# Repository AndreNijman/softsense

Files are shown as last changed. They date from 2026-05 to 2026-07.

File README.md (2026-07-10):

# SoftSense — underwater self-sensing soft gripper

> 🏆 **Project complete (July 2026) — prize winner.** The full SoftSense project
> took home a prize at its competition. This repository is the finished,
> consolidated record: parametric CAD, FEA campaigns, the grip-texture and
> actuator studies, print profiles, ESP32 firmware and the Orange Pi
> controllers — everything in one place. (Formerly `gripper-cad`; the old
> GitHub URL redirects. The judge-facing engineering document is
> `SoftSense_Innovations_Documentation.docx`.)

<p align="center">
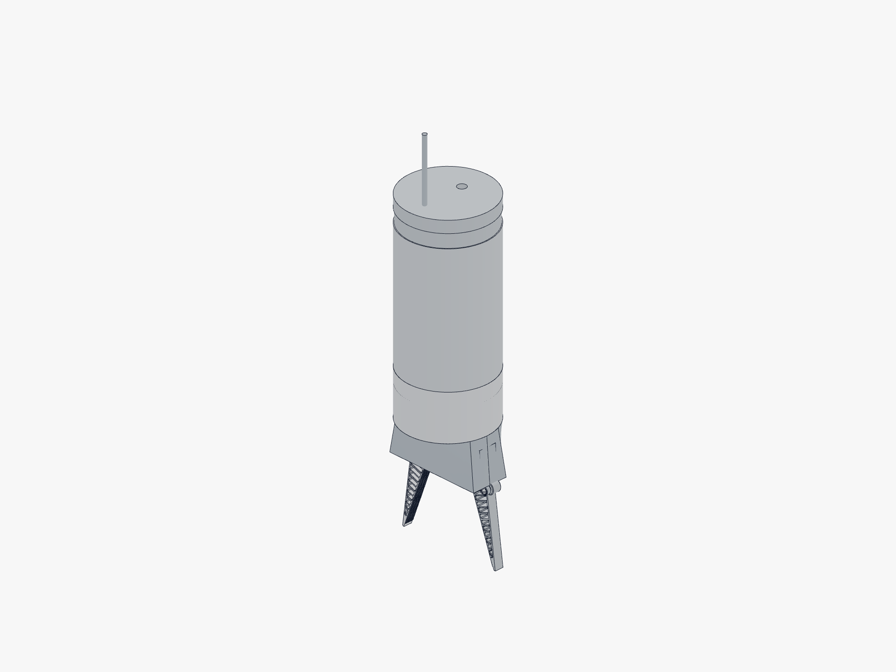
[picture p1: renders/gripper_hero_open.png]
SoftSense gripper, open
  
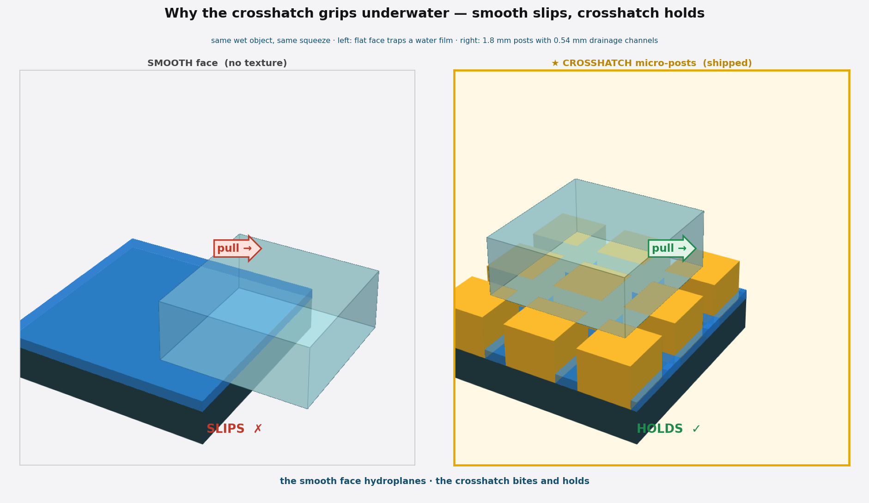
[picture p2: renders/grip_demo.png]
Grip demo — finger wrapping an object
  
  <br>
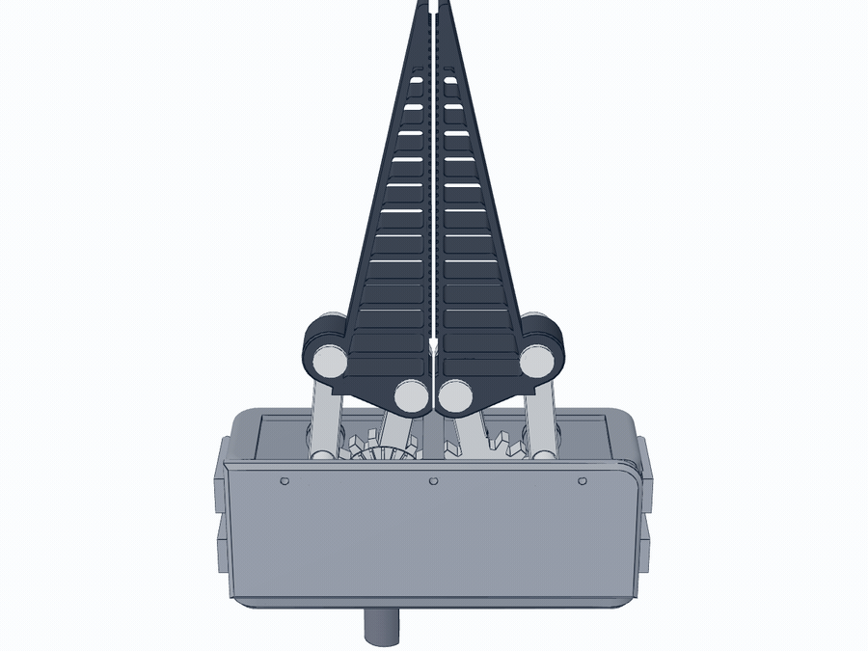
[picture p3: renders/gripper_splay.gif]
Open/close splay animation
  
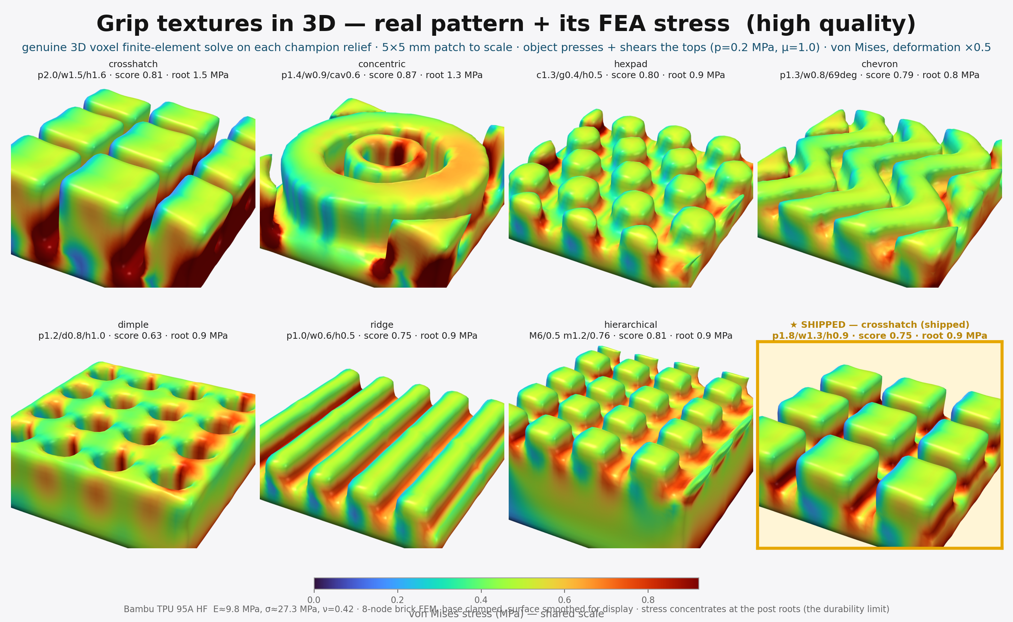
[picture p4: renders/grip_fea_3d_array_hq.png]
Voxel contact-FEA array
  
</p>

A robotic gripper with working single-DOF motion: **rotate one input shaft and
both fingers open/close symmetrically, splaying outward as they open.** The
jaws are **Fin Ray-style compliant fingers** (3D-printed in TPU with a
crosshatch micro-post grip texture) that bend and wrap *around* a grasped
object. The gear/linkage drive lives in a **flooded enclosure** designed for
**underwater** use (drain/flood holes, corrosion-resistant material choices —
`docs/UNDERWATER.md`).

**The SoftSense idea:** there is no dedicated force sensor. The **actuator is
the grip-force sensor** — motor current → torque → tip force through the
calibrated kinematic chain (`motor/SENSING.md`). The printed drivetrain is the
structural limit (`T_safe`), and the motor's current limit is its protection.

## Mechanism (one DOF)

- Two equal **spur gears** mesh on the centreline. The left gear (A_L) is
  driven through a **90° straight bevel pair**: a 12-tooth bevel gear fused on
  A_L's +Z face, driven by an integral 6-tooth bevel pinion (2.0 ratio,
  **module 1.8, 25° PA** — deliberately coarse, thick teeth from the gear-FEA
  strength pass) on a vertical **Ø15 input shaft**, so the drive **enters the
  housing from the bottom** while the fingers point up. The mesh
  counter-rotates the right gear: one shaft moves both fingers as a mirror pair.
- The input shaft's bottom end carries a **female Feetech 25T spline socket**
  (Ø5.9 serration, press-fit) — a **Feetech STS3250** bus servo presses
  straight in, no adapter horn. Caliper-verify the spline and print the fit
  coupon before committing (`gripper.py`, `SPLINE_*`).
- Each gear is the **crank of a non-parallelogram four-bar linkage**; the
  finger is rigid with the coupler. The link lengths give translate-apart
  **+ ~18° outward splay** over the travel, clear of any four-bar dead-point.
- Travel: closed (jaw faces ~1.6 mm apart) → open (~60 mm at the base,
  ~118 mm at the fingertips) at 1× scale.

## Fin Ray fingers (TPU)

Each finger is a compliant triangular truss — thin 1.2 mm contact beam, sharply
tapered 1.8 mm spine, 14 fine reversed-slant ribs — chosen by **multi-shape FEA**
to grasp **universally**: it distributes contact pressure along the whole finger
on flat/large objects and grips round objects evenly across a wide size range
(`fea/UNIVERSAL_FINGER.md`). The contact face carries a **crosshatch micro-post
grip texture** (1.8 mm posts + 0.54 mm drainage channels) — the empirical winner
among textures that actually tile the 10 mm blade, chosen by a wet-grip physics
model + sensitivity campaign with an honestly-documented override of the model's
raw winner (`grip/GRIP_TEXTURE.md §5`). Printed in **Bambu TPU 95A HF**
(measured ISO 527 data; ether-based TPU recommended for sustained immersion).

## Enclosure (flooded, underwater)

Rounded hollow housing; the vertical input shaft exits through two journal
bearings in the bottom wall, surrounded by a mounting flange with **4 × M4
bolt holes**. **Drain/flood holes** let it flood and drain — no trapped air,
pressure equalizes with depth. Top slots are sized to the measured arm sweep.

## Electronics & control

| Where | What |
|---|---|
| `firmware/` | **ESP32 controller (the shipped one)** — Waveshare General Driver for Robots. Boots its own Wi-Fi AP + captive web UI (OPEN/CLOSE, slider, live position/load/voltage/temp, on-flash calibration), drives the STS3250 on the built-in bus-servo port. **Stop-on-load** (gentle stop-on-contact) ported from the Pi controller. |
| `firmware/gamepad/` | **DualSense bridge** — a laptop-side script + page that turns a PS5 pad into a jog controller via the firmware's `/api/jog`. |
| `opi/` | **Orange Pi controllers** (3 LTS Wi-Fi-AP appliance + Ethernet-only Orange Pi PC/H3 variant) — the original offline web controller with stop-on-load, vendored pyserial, provisioning + deploy scripts. Superseded by the ESP32 after the Pi died, kept as a complete working alternative. |
| `motor/` | The **actuator & sensing study**: requirements → 12-agent survey → weighted selection (±50% sensitivity). Depth-rated pick: DYNAMIXEL XW540-T260; the built demonstrator runs the Feetech STS3250 direct-spline mount. Power chains per interface in `motor/POWER_SUPPLY.md`. |

## Repository map

| Path | What it is |
|---|---|
| `gripper.py` | **Source of truth** — parametric build123d generator + four-bar solver + Fin Ray finger + enclosure. Env: `GRIPPER_OPEN` 0–1 (pose), `GRIPPER_FINGER_SCALE` 0.6–2.5, `GRIPPER_SCALE` (whole-gripper scale-up). |
| `docs/TESTING_AND_SIMULATION.md` | **How everything was tested & simulated** — judge-facing account of every simulation, its physics, what it proves, fidelity honesty, reproduce commands. Start here for "how do you know it works?". |
| `docs/` | Engineering guides: assembly, BOM, DFM, underwater, printing, print profiles, materials, testing, scale-up (`SCALE_UP.md`), the overnight honest-framing fixes (`OVERNIGHT_FIXES.md`). |
| `fea/` | **Finger FEA campaign** — universal-finger study, scalability, underwater crush, decision log (~90 runs), 3D corotational contact solver (CPU+GPU). |
| `grip/` | **Grip-texture campaign** — wet-grip surrogate model, sweep + ±50% sensitivity, Tier-2 contact FEA, literature validation gate, decision log. |
| `motor/` | **Actuator/sensing/integration campaign** — requirements, survey, selection, drivetrain gear FEA (`T_safe`), force-via-current sensing, electrical, ROV integration, bench-test plan, FMEA, mounting-interface dossiers + 7 modelled adapters (`motor/cad/adapters/`), power supply. |
| `parts/` + `output/` + `print_plates/` | Per-part STEP/STL exports (with `MANIFEST.md`), material-labelled print set, and plate STLs. |
| `variants/scale_1.5x/`, `variants/scale_2.0x/` | **Scaled-up variants** (fully re-simulated; parts + plates + 3MF print-ready). See `docs/SCALE_UP.md`. |
| `profiles/` | Importable Bambu Studio filament + process profiles (TPU 95A HF on P1S, 0.4 mm hardened nozzle). |
| `derived/` | Regenerable assemblies: static poses (`gripper_{closed,mid,open}.step`) + interactive slider STEPs. |
| `renders/` | Final animations, heroes, FEA montages, adapter snapshots. |
| `motor/cad/output/system_assembly_T2_*.step` | **Full integrated system** (gripper + canister + servo + shaft + seal + penetrators), one STEP per servo option. |
| `firmware/`, `opi/` | Controllers — see table above. |
| `scripts/`, `regen.sh` | Export/plate/render helpers; `./regen.sh` rebuilds all derived artifacts. |
| `SoftSense_Innovations_Documentation.docx` | The competition documentation deliverable. |

## Print & build

**25 printed parts, zero purchased hardware, zero fasteners** — the only tool
is a soldering iron. 9 structural parts (PA12-GF rigid set + TPU fingers), the
one-piece `input_pinion_shaft` (bevel pinion + Ø15 shaft + STS3250 spline
socket), 8 heat-stake pins and 8 retaining caps (PETG-HF): each journal pin is
retained by a cap melted over its stud into a thermal-rivet head wider than
the bore. Print settings + rationale: `docs/PRINT_PROFILE_P1S_TPU.md`,
`docs/PRINTING.md`, `docs/DFM.md`.

## Regenerate / re-pose

```bash
source /home/andre/.cad-venv/bin/activate          # build123d + OCP toolchain
STEP=/home/andre/.claude/skills/cad/scripts/step
GRIPPER_OPEN=0.7 python $STEP gripper.py -o derived/gripper_open70.step   # any pose 0..1
GRIPPER_SCALE=1.5 python $STEP gripper.py -o derived/gripper_15x.step     # scaled build
python gripper.py                                  # numeric kinematic self-check
./regen.sh                                         # full rebuild (poses + parts + plates + renders)
```

The FEA solver has a CuPy GPU backend (`GRIPPER_FEA_GPU=1`), but at these mesh
sizes (≤25k DOF) CPU is faster — the GPU only wins past ~100k DOF.

### Interactive viewer

Open `derived/gripper_interactive.step` in CAD Explorer and drag the **`open`**
slider (= turning the shaft); mesh and edges move together live.

## Coordinate convention

`X` = jaw open/close (right +), `Y` = toward fingertips (up +),
`Z` = depth = revolute & gear axes. Units: mm.

## Assumptions / caveats

- **Off-centre drive.** A single shaft drives both jaws symmetrically only if
  the two gears mesh each other, so the input enters at the left pivot (A_L);
  the right-angle bevel stage redirects it to the vertical bottom-exit shaft
  without changing the finger kinematics.
- **Fin Ray-style, not Festo's patented variant** — the generic
  adaptive-compliant slanted-rib truss principle, not the *Fin Ray Effect®*
  tooth-shape variant.
- Gear tooth forms are **representative** (straight-flank, clean meshing pitch
  circles), not production involutes — coupon-tunable for backlash/contact
  before a real run. The STS3250 spline socket dims are research-inferred:
  **caliper-verify a real servo + print the fit coupon first.**
- Real compliant grip (wrap-around) is a TPU material behaviour — the CAD
  shows the undeformed finger; the motion model opens/closes it rigidly.
- Dimensions were inferred from one reference image, not measured hardware.

## Honest framing on the published headlines

- The finger-FEA **12 N target** is a **stress-probe load** used to rank
  finger designs, **not** an operating force the drivetrain delivers. The
  printed right-angle stage caps input torque at `T_safe` — quantified on the
  crown-era teeth at ≈ 0.013 N·m (radial 2D) / 0.034 N·m (single-station 2D),
  mapping to a per-finger **operating band of 0.14 – 0.73 N**. The shipped
  bevel pair was upsized (module 1.0 → 1.8, ~+90 % tooth thickness) by the
  same strength pass and should raise that ceiling, but **the only bench-grade
  number is the printed-coupon torque-to-failure test** in
  `motor/BENCH_TEST.md`. Run `motor/scripts/drivetrain_force_envelope.py` for
  live numbers.
- The "**5.7 – 8.6× safety margin**" was computed with linear tetrahedra that
  volumetrically lock near ν = 0.5; the locking-stable P2 re-run puts the
  corrected margin nearer **3.8 – 5.7×** at the 12 N probe — and ≈ **120 – 365×**
  at the actual drivetrain-deliverable force. Design call unchanged; the
  absolute number is corrected (`docs/OVERNIGHT_FIXES.md`).
- The Tier-1 grip-texture model is **rank-only**, its literature gate is a
  sufficient-condition check, and the shipped crosshatch won only after a
  documented geometric-tileability override of the model's raw winner
  (`grip/GRIP_TEXTURE.md §5`, `grip/GRIP_MODEL.md`).
- `T_safe` is a 2D upper bound; the right-angle stage is genuinely 3D and
  straight-flank teeth will gall/edge-load in PA12-GF rather than roll
  cleanly. Bench coupons are the ceiling that counts.

## License

**CC BY-NC-ND 4.0** — you may view, download, build, and share this work
**with attribution, for non-commercial purposes, without distributing
modified versions**. Commercial use and derivative redistribution rights are
reserved; contact the author to arrange a commercial license. See `LICENSE`.

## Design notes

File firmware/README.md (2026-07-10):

# Gripper controller — ESP32 firmware

Firmware for the **Waveshare General Driver for Robots** (ESP32-WROOM-32,
Core Electronics WS-23730). The board boots into its own Wi-Fi access point;
you join it from your phone, open a web page, and get OPEN / CLOSE buttons for
the Feetech servo. **Fully offline** — no router, no internet.

This replaces the fried Orange Pi controller: the ESP32 *is* the AP, the web
server, and the servo bus master, all in one board.

## How you use it

1. Power the board from **~12 V (3S)** via the XH2.54 DC input (the bus servo
   power comes from this rail — a 12 V STS3250 wants ~12 V).
2. It broadcasts Wi-Fi **`Gripper`** / password **`gripper1234`** (published
   defaults — change `AP_SSID`/`AP_PASS` in `src/main.cpp` before flashing if
   that matters for your build).
3. Join it on your phone → a captive "sign in" page pops up (or open
   **http://192.168.4.1/**).
4. Tap **OPEN** / **CLOSE**. Live position / load / voltage / temp show below;
   a 0.91" OLED on the board mirrors the SSID, IP, and position.

### Calibrate open & close
The shipped open/close positions (1024 / 3072 of 0–4095) are placeholders.
1. Turn **Torque** off (or use the slider with torque on) and move the gripper.
2. At the fully-open pose tap **Set current as OPEN**; at fully-closed tap
   **Set current as CLOSE**. Saved to the ESP32's flash (NVS); survives reboots.

## Wiring the servo

The Feetech **STS3250** (or STS3215) plugs **straight into the board's ST3215
bus servo port** with a 3-pin cable — no FE-URT-1 adapter. The board provides
both the half-duplex data line and servo power from the DC input.

- Bus servo UART: **GPIO18 (RXD) / GPIO19 (TXD)**, **1,000,000 baud**, servo
  **ID 1** (Feetech factory default).
- ⚠️ Before powering up, check the 3-pin connector orientation
  (**GND / VCC / signal**) matches between the servo cable and the board port —
  reversed power can damage the servo.
- ⚠️ Match the supply voltage to the servo (12 V servo → ~12 V / 3S; a 7.4 V
  STS3215 variant → ~7.4 V, **not** 3S).

## Flashing (do this when the board arrives)

Connect the board to this laptop with **USB-C** (the ESP32 port — the one wired
to the CP2102 that talks to the ESP32), then:

```bash
firmware/flash.sh            # auto-installs PlatformIO via pipx if missing
# or, manually:
cd firmware && pio run -t upload
pio device monitor           # 115200 — see the boot log
```

`board = esp32dev` (ESP32-WROOM-32) is already set in `platformio.ini`. If
upload fails to auto-reset, hold **BOOT**, tap **EN/RST**, release **BOOT**, and
re-run. Pass an explicit port with `firmware/flash.sh /dev/ttyUSB0`.

### Arduino IDE alternative
1. Install the **esp32** boards package (Boards Manager).
2. Copy `firmware/lib/SCServo` into your Arduino `libraries/` folder; install
   **Adafruit SSD1306** + **Adafruit GFX** from Library Manager.
3. Open `firmware/src/main.cpp` as a sketch (rename to `Gripper.ino` in a
   `Gripper/` folder), select **ESP32 Dev Module**, and Upload.

## What's here

```
firmware/
  platformio.ini        # build config (board, libs)
  flash.sh              # build + upload wrapper
  src/
    main.cpp            # AP + captive web server + servo control + OLED
    index_html.h        # mobile UI, embedded in flash (served at /)
  lib/SCServo/          # Feetech bus-servo library (bundled, from Waveshare)
```

## HTTP API (same shape as the old OPi controller)

| Method | Path | Action |
|---|---|---|
| GET  | `/api/status` | JSON: connected, position, load, voltage, temp, open/close/speed/acc |
| POST | `/api/open` · `/api/close` | move to the calibrated endpoint |
| POST | `/api/goto?pos=N` | move to raw position 0–4095 |
| POST | `/api/torque?on=0\|1` | enable/disable holding torque |
| POST | `/api/calibrate?which=open\|close` | save current position as that endpoint |
| POST | `/api/config?speed=&acc=&open=&close=` | set + persist params |

## Notes / untested until hardware boots

- Bus pins, baud, and the `SMS_STS` protocol are from Waveshare's own firmware
  for this exact board, so they should be correct out of the box.
- Open/close **directions and positions are placeholders** — calibrate on first
  run.
- The OLED is assumed 128×32 @ I²C `0x3C` on GPIO32/33. If your board's panel
  differs it just stays blank (non-fatal); set `USE_OLED 0` in `main.cpp` to drop
  the dependency entirely.
- To change the Wi-Fi name/password, edit `AP_SSID` / `AP_PASS` in `main.cpp`
  and re-flash.

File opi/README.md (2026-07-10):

# Gripper controller — Orange Pi 3 LTS appliance

A self-contained, **offline** controller for the gripper's Feetech servo. The
Orange Pi boots straight into a Wi-Fi access point; you join it from your phone,
open a web page, and get OPEN / CLOSE buttons (plus manual positioning and
calibration). The Pi is **never on a real network** — the only time it changes
is when you plug it into the dev laptop over Ethernet and push new code.

## How you use it

1. Power the Pi. After ~30 s it broadcasts Wi-Fi **`Gripper`** (password
   **`gripper1234`**).
2. Join that Wi-Fi on your phone. A "sign in to network" page should pop up
   automatically (captive portal). If not, open **http://10.42.0.1/**.
3. Tap **OPEN** / **CLOSE**. Live position / load / voltage / temperature show
   under the buttons.

### Calibrating open & close
The shipped open/close positions (1024 / 3072 of 0–4095) are placeholders.
To set them to your gripper's real endpoints:
1. Toggle **Torque** off, hand-move the gripper (or use the slider with torque on).
2. Drive it to the fully-open pose, tap **Set current as OPEN**.
3. Drive it to the fully-closed pose, tap **Set current as CLOSE**.
Saved to `config.json` on the Pi; survives reboots and future deploys.

## Hardware

- **Board:** Orange Pi 3 LTS (Allwinner H6), Armbian (Debian trixie).
- **Servo:** Feetech **STS3250** (STS3215 also works) on the SCS-TTL bus.
- **Adapter:** Feetech **FE-URT-1** (CH340 USB-serial) → the Pi's USB port,
  enumerates as `/dev/ttyUSB0` (also symlinked `/dev/feetech`), 1,000,000 baud.
- **Power:** 12 V to the URT-1 screw terminal / servo rail (separate from the
  Pi's 5 V supply). The servo ID is **1** (Feetech factory default).

## Networking (fixed by design)

| Interface | Role | Address |
|---|---|---|
| `wlan0` | Wi-Fi AP (hostapd + dnsmasq) | `10.42.0.1/24`, DHCP `.10–.200` |
| `eth0`/`end0` | Wired deploy link to laptop | `192.168.7.2/24` |

No internet, no routing, no upstream DNS — all DNS resolves to the Pi so the
captive portal works.

## Deploying new app code

Edit anything under `opi/app/`, then plug the Pi into this laptop with an
Ethernet cable and run:

```bash
opi/deploy.sh
```

It sets the laptop NIC to `192.168.7.1`, rsyncs `app/` → `/opt/gripper`, and
restarts `gripper-web`. Your on-device `config.json` (calibration) is preserved.
SSH is `root@192.168.7.2`, key-only from this laptop (console password `gripper`).

> **If you build one of these:** the published defaults — console root password
> `gripper` and AP passphrase `gripper1234` (`system/hostapd.conf`) — are known
> to anyone reading this repo. SSH is key-only so they only matter at a local
> console / within AP range, but change both (`passwd` on the Pi + edit
> `hostapd.conf`) before using it anywhere shared.

## (Re)flashing the whole appliance

With a card that already has Armbian for this board, mounted at
`/run/media/$USER/armbi_root`:

```bash
opi/provision.sh
```

This wipes the prior owner's config, installs hostapd/dnsmasq (via qemu-chroot),
lays down the AP + web app + deploy link + this laptop's SSH key, sets the
hostname to `gripper`, and enables everything. Eject and boot.

## Layout

```
opi/
  app/                 # what runs on the Pi, lives in /opt/gripper
    server.py          # stdlib HTTP control server on :80
    servo.py           # Feetech STS protocol driver (pure Python)
    index.html         # mobile control UI
    config.json        # port/baud/id + open/close/speed/acc (calibratable)
    vendor/serial/     # vendored pyserial (no pip on the offline Pi)
  system/              # OS config installed into the rootfs
    hostapd.conf  dnsmasq-gripper.conf  default-hostapd
    systemd-networkd/  gripper-web.service  99-feetech.rules
  provision.sh         # one-shot: turn an Armbian card into this appliance
  deploy.sh            # push app code over the wired link
```

## Troubleshooting

- **No `/dev/ttyUSB0`:** the CH340 can be grabbed by `brltty` (not installed
  here) or ModemManager. The udev rule sets `ID_MM_DEVICE_IGNORE`. Re-plug the
  URT-1 and check `dmesg | tail`.
- **UI loads but "servo not found":** the web app runs fine without the servo.
  Check 12 V power, the 3-pin lead, and that the servo ID is 1
  (`/api/status` reports `connected:false` until it answers).
- **Wi-Fi doesn't appear:** `systemctl status hostapd` over the wired link.
- **STS vs SCS:** this driver speaks the little-endian STS/SMS protocol
  (STS3215/3250). SCS-series servos use big-endian and need a tweak.

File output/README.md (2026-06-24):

# Print set (output/)

Each filename is `<part>_x<qty>_<material>.stl`: the part, how many to print, and the FINAL material to print it in (BOM.md §5).

| File | Qty | Material |
|---|-----|---|
| `enclosure_x1_PA12-GF.stl` | 1 | PA12-GF |
| `front_cover_x1_PA12-GF.stl` | 1 | PA12-GF |
| `drive_arm_R_x1_PA12-GF.stl` | 1 | PA12-GF |
| `drive_arm_L_x1_PA12-GF.stl` | 1 | PA12-GF |
| `input_pinion_shaft_x1_PA12-GF.stl` | 1 | PA12-GF |
| `follower_x2_PA12-GF.stl` | 2 | PA12-GF |
| `finger_R_x1_etherTPU-95A.stl` | 1 | etherTPU-95A |
| `finger_L_x1_etherTPU-95A.stl` | 1 | etherTPU-95A |
| `melt_pin_axle_AR_x1_PETG-HF.stl` | 1 | PETG-HF |
| `melt_pin_axle_AL_x1_PETG-HF.stl` | 1 | PETG-HF |
| `melt_pin_axle_B_x2_PETG-HF.stl` | 2 | PETG-HF |
| `melt_pin_finger_C_x2_PETG-HF.stl` | 2 | PETG-HF |
| `melt_pin_finger_D_x2_PETG-HF.stl` | 2 | PETG-HF |
| `melt_cap_x8_PETG-HF.stl` | 8 | PETG-HF |

**14 unique parts, 25 physical prints total.**

Materials: PA12-GF (rigid body/gear parts), PETG-HF (all 8 pivot pins + 8 melt-on caps -- heat-staked with a soldering iron), ether-based TPU ~95A (the 2 Fin Ray fingers -- never ester-TPU, it hydrolyzes underwater).

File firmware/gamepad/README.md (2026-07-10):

# DualSense control for the gripper

Control the gripper with a PlayStation DualSense (or DualShock 4). The controller
connects to **your laptop** — a laptop-side bridge reads it and sends commands to
the board over Wi-Fi.

## Why it can't plug into the board

- **The driver board's USB-C port can't read a controller.** It's an ESP32-WROOM-32
  (no USB-host hardware at all) and that port is just a **CP2102 UART bridge** for
  flashing. A gamepad is a USB *host* job the board can't do.
- **A page served *from* the board can't read the gamepad either.** Browsers gate the
  Gamepad API behind a **secure context**; on the board's plain-http IP
  `navigator.getGamepads()` returns nothing. It only works from **`http://localhost`**
  (or https).

So the controller plugs into the **laptop** (USB-C cable, or the laptop's Bluetooth),
and the laptop relays to the board. Two ways to do that:

## Option A — browser page (recommended)

```bash
./serve.sh                 # serves the page from http://localhost:8080
```
1. Join the board's Wi-Fi **`Gripper`** (so the page can reach `192.168.4.1`).
2. Plug the DualSense into the laptop (USB) or pair it over the laptop's Bluetooth.
3. Open **http://localhost:8080/**, set the Board URL (`192.168.4.1` ESP32 /
   `192.168.7.2` Orange Pi), and **press any controller button** to activate it
   (browsers require one button press first).

Uses the browser's normalized "standard" gamepad mapping, so it's consistent across
USB and Bluetooth. Shows live position/load and a debug readout.

## Option B — native bridge (no browser)

```bash
python3 bridge.py                    # ESP32 (192.168.4.1)
python3 bridge.py --host 192.168.7.2 # Orange Pi over Ethernet
python3 bridge.py --debug            # print raw button/axis numbers to remap
```
Pure standard library (reads `/dev/input/js0`). Fewer steps, but the raw
button/axis numbers vary by USB vs Bluetooth and kernel — run `--debug` once, press
each control, and if they don't match, edit the `BTN_*` / `AXIS_*` constants at the
top of `bridge.py`.

## Controls

| Input | Action |
|---|---|
| **R2** (right trigger) | proportional grip — release = open, squeeze = close |
| **Left stick ↕** | fine jog (when R2 released) |
| **✕ Cross** | Open |
| **◯ Circle** | Close (uses stop-on-load if enabled) |
| **L1** | STOP — brake & hold |
| **□ Square** | Torque on (bridge) / toggle Torque (web) |
| **△ Triangle** | Stop-on-load on (bridge) / toggle (web) |

Live trigger control uses **`/api/jog`** (a raw, non-blocking move) so streaming stays
responsive even with stop-on-load enabled; the **Circle** button uses the guarded
`/api/close` so a deliberate grip still contact-stops.

## Firmware requirement

Needs the board firmware with the `/api/jog` endpoint and the `Access-Control-Allow-Origin`
header (added alongside this). Reflash with `firmware/flash.sh`. Without it, live jog and
the browser page's live readout won't work (buttons still would, via no-CORS).

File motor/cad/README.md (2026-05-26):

# motor/cad — every bought + printed actuator-system part, in CAD

Each component referenced by the BOM's actuator-system row is modelled
parametrically here as a `build123d` envelope (cited dimensions, not
manufacturer-equivalent CAD), so the whole gripper-plus-canister-plus-
actuator stack can be assembled, clearance-checked, and rendered in one
file.

## Files

| file | what |
|---|---|
| [`external_parts.py`](external_parts.py) | 13 bought parts: 4 servos (XW540 / XM540 / STS3250 / STS3215), 3" canister (tube + 2 end caps), WetLink penetrator + blank M10 plug, lip seal, goBILDA shaft, KTR MINEX-S magnetic coupling, DIY N52 rotor. Every dimension cited to its primary source in the docstring. |
| [`printed_adapters.py`](printed_adapters.py) | 5 printed parts the BOM names but `gripper.py` doesn't model: `servo_horn_adapter` (dry side), `wet_d_socket` (wet side, mates the gripper coupler), `servo_cradle` (locates servo inside the 3" tube), `cradle_endcap_spacer`. Surfaces the `servo_cradle` design gap the BOM hadn't itemised. |
| [`system_assembly.py`](system_assembly.py) | Integrated assembly. Brings the **existing gripper** (via `gripper.gen_step()`) plus every external + printed part into one Compound. Variants: `T2` (lip-seal, primary), `T3` (magnetic-coupling fallback), `LINEUP` (side-by-side servo choices). Asserts headroom > 0 inside the canister. |
| `output/*.step` | One STEP per part + one per assembly. |
| `output/hero_T2_STS3250.png` | Hero render of the primary integrated assembly. |

## Build everything

```bash
source ~/.cad-venv/bin/activate

# individual parts (smoke test)
python motor/cad/external_parts.py
python motor/cad/printed_adapters.py

# integrated assemblies (T2 PRIMARY first)
GRIPPER_CANISTER_VARIANT=T2 GRIPPER_CANISTER_SERVO=STS3250 \
    python ~/.claude/skills/cad/scripts/step motor/cad/system_assembly.py \
    -o motor/cad/output/hero_T2_STS3250.step

# T3 magnetic-coupling fallback
GRIPPER_CANISTER_VARIANT=T3 python motor/cad/system_assembly.py

# four-servo lineup
GRIPPER_CANISTER_VARIANT=LINEUP python motor/cad/system_assembly.py

# hero render
python ~/.claude/skills/render/scripts/snapshot \
    --input motor/cad/output/hero_T2_STS3250.step \
    --output motor/cad/output/hero_T2_STS3250.png \
    --size-profile assembly
```

## Coordinate frame

The gripper `gen_step()` reorients by +90X so fingers point world +Z.
Every part in `system_assembly.py` is placed in that same world frame:

- fingers at `+Z`
- gripper input D-coupler exits the flange face at world `(x, y, z) = (-12, -11.72, -25)`
- canister axis = world `Z`, hanging straight down from the gripper
- penetrators exit world `-Z` (downward) out of the dry end cap

## Honesty caveats

- All bought-part dims are **datasheet envelopes** for clearance checks,
  not manufacturer-replacement CAD. Caliper-verify before final fit.
- The STS3250 case dims (20 × 54 × 47 mm) were inferred from Feetech
  catalogue cross-reference + distributor photos — OpenELAB's product
  page does not publish them. Tagged APPROXIMATE in the source.
- Blue Robotics end-cap exact flange OD / mating-boss geometry was not
  in the public spec table; we used 98 mm flange OD, 7 mm boss insertion,
  consistent with photos and the 3" series' published `K` screw-PCD of
  ~63.5 mm. CAD package from the BR tech-details download is the authoritative
  source for production drawings.
- The integrated assembly's `assert headroom > 0` confirms the servo +
  cradle + horn-adapter stack fits inside the 240 mm tube with at least
  ~150 mm of cable-bend slack on all four servo options. If you swap
  to a longer servo or shorter tube, the assertion is your sentinel.

## Cross-links

- BOM canister row → `../../BOM.md` (line ~185)
- Architecture rationale → `../ROV_INTEGRATION.md` §2c–§2d
- Selection rationale → `../SELECTION.md`, `../MOTOR_STUDY.md`

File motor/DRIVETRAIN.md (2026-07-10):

# Drivetrain — ratio rationale + gear-tooth FEA under motor stall

Phase 4 revisited the crown/pinion + sector-gear stage against the selected
actuator (`SELECTION.md`) and ran a structural FEA of the printed teeth. The
brief's instinct was right: *the drivetrain in `gripper.py` was a blocky
representative prototype.* This phase replaces representative-by-eye with
analysis — and the headline finding is significant.

> **Headline.** The compact **right-angle crown/pinion stage is the binding
> structural limit of the entire gripper.** At the small radii the housing allows,
> the printed teeth carry far less torque than a 12 N tip grip demands. The fix is
> (a) the **face-width strengthening implemented + build-verified here**, plus (b) a
> **module/radius re-size specified as a proposed engineered target** (needs CAD
> clearance validation), with (c) the **motor current-limit (the sensing pivot)
> enforcing the safe ceiling in firmware**. This is *why* the magnetic-coupling
> fallback (whose pole-slip torque scales with coupling diameter, not housing
> radius) looks strong in retrospect.

Reproduce: `python motor/scripts/gear_fea.py` (→ `motor/iterations/_gear_fea.json`),
`python motor/scripts/check_drivetrain.py` (interference), `python gripper.py`
(four-bar self-check).

---

## 1. Method

- **Headline = 2D plane-stress FEA** of the actual straight-flank tooth (`gear_fea.py`,
  porting the grip Tier-2 Q4 machinery, `grip/scripts/texture_fea.py`). A worst-case
  **tip tangential load** bends a cantilever tooth (root thickness `s_root`, height
  `h`, loaded face width `b_eff` = min of the two mating faces); peak von-Mises is
  sampled in the root band (sharp shoulder → conservative; a real fillet lowers it).
- **Lewis "cross-check" disclosure.** The earlier framing presented "Lewis 40 vs FEA
  38 MPa → no bug" as cross-validation. It isn't: Lewis assumes a 14.5° / 20°
  **involute spur tooth** form factor, and our teeth are *representative straight-
  flank, not involute* (`gripper.py` notes). Two wrong models that agree are not
  the same as one right model being confirmed. The Lewis cross-check is at best a
  same-formulation consistency check (both are 2D Bernoulli cantilevers at the
  pitch radius), not independent validation.
- **Crown gear is a 3D problem, not a 2D plane-stress tooth.** A real crown / face
  gear has a tangential tooth thickness `s_root(r)` that varies with radial
  station, a contact line that sweeps radially under rotation, and a load that
  decomposes into tangential + radial + axial components — none of which the
  shipped 2D plane-stress single-station FEA captures. `gear_fea_radial.py`
  (added on this branch) runs the same 2D FEA at five radial stations across the
  crown's `2·CROWN_TOOTH_H` extent and reports the worst (inner-radius) station.
  Result: the inner-edge slice carries the binding stress and `T_safe(crown)`
  drops from **0.034 N·m → 0.013 N·m** — a **2.6× tighter upper bound** on what
  the printed teeth can carry. This is still not a real 3D solve (the base disk's
  bending compliance and the moving contact line are still missing). The only
  bench-grade ceiling is the printed-coupon torque-to-failure test in
  `motor/BENCH_TEST.md`.
- **Allowable σ = 30 MPa** (PA12-GF, the drive-arm + pinion material per `BOM.md`).
  Basis: Polymaker Fiberon **PA6-GF25 = 84.5 MPa** tensile (ISO 527); PA12 base is
  weaker than PA6, FDM 100 %-infill knocks bulk down ~30–40 % (layer adhesion) →
  ~50–65 MPa, and a wet/creep/cyclic safety factor brings the **root-bending
  allowable to a conservative 30 MPa** (cf. the grip campaign's `STRENGTH = 25` for
  Bambu TPU 95A HF).

## 2. The torque the teeth must carry

From the kinematics (`REQUIREMENTS.md`): a 12 N tip grip needs left-gear torque
`T_left = 2·T_finger ≈ 1247 N·mm`. The crown/pinion **contact force depends only on
the crown pitch radius** (the i_g split is irrelevant to the tooth force):

`F_contact = T_left / CROWN_RC`.

| | ideal (η=1) | realistic (η≈0.5) |
|---|---|---|
| input torque T_motor for 12 N tip | 0.47 N·m | **0.94 N·m** |
| F_contact at the crown/pinion (CROWN_RC = 8) | 156 N | **≈ 313 N** |

(The losses sit *downstream* of the gears, so the crown/pinion sees the full
η-adjusted motor torque — the realistic column is the honest one.)

## 3. Result — T_safe (input-shaft torque at which the weakest tooth reaches 30 MPa)

| geometry | pinion | crown (single-station 2D) | crown (radial 2D, inner edge) | sector | **binding T_safe** |
|---|---|---|---|---|---|
| **as-was** (PINION_T 4, CROWN_TOOTH_H 1.6, b_eff 3.2) | 0.02 | 0.02 | — | 0.21 | **0.02 N·m** |
| **shipped** (PINION_T 8, CROWN_TOOTH_H 3.0, b_eff 6.0) ✓ | 0.04 | 0.034 | **0.013** | 0.21 | **0.013 N·m** (radial) / **0.034 N·m** (single-station) |
| **proposed re-size** (CROWN_RC 11, m 1.83, 12/6 teeth, face 8) ⚠ | — | — | — | — | **0.40 N·m** (single-station conservative) |

The sector gear (chunky m≈1.5) is robust; the **crown then pinion** are the weak
links, exactly as expected for a 9-tooth, 0.67-module pinion below the involute
interference limit. **Face-width doubling roughly halves root stress but the tiny
module dominates** — T_safe only rises 0.02 → 0.034 N·m, still ≪ the 0.94 N·m
working torque. **Strengthening alone is insufficient; the module/radius re-size is
required**, and even it (T_safe ≈ 0.4–0.8 N·m) only *approaches* the working torque,
because `CROWN_RC` is capped at ~11 by the sector teeth (which reach R_GEAR + 0.45·H
= 13.35).

## 4. Ratio decision — KEEP 24/9 = 2.667:1

The **rock-bottom budget servo in the ladder** — Feetech STS3215, cont. 0.98 N·m —
is the binding floor: at 2.667:1 it reaches 12 N at the **tip** continuous; dropping
to 2.2:1 it falls to ~11.4 N and the budget option no longer hits 12 N. So the
ratio is **revisited and deliberately kept** — the real Phase-4 change is
*engineered teeth* and a *derived current ceiling*, not a ratio tweak. (The
proposed re-size's geometry happens to land at i_g 2.0 as a by-product of the
bigger module + fewer teeth — a ~5 % grip-at-tip reduction for the STS3215,
accepted as the structural price; the **deep-budget STS3250 (cont ~2.45 N·m)**
and **value-tier XM540-W270 (cont 2.12 N·m)** and **flight XW540-T260 (cont
1.9 N·m)** all have ample torque headroom over the ratio and are not constrained
by it.)

## 5. What was implemented vs proposed

- **Implemented + build-verified (`gripper.py`):** `PINION_T 4.0 → 8.0`,
  `CROWN_TOOTH_H 1.6 → 3.0`. Pitch radii, mesh depth and the four-bar are untouched.
  - `check_drivetrain.py`: **no new collisions** at open = 0/0.5/1 — all moving
    pairs 0 mm³; pinion∩enclosure = 0.476 mm³ is the pre-existing shaft-in-journal
    running fit (the widened pinion at Y −12..−4 sits above the bores at −13.5, so it
    adds nothing; constant across poses ⇒ static).
  - `gripper.py` four-bar self-check **identical** to before (gaps/rotations
    unchanged) — confirms the kinematics are untouched.
- **Proposed / not implemented (numbered option `DECISION_LOG.md` D10-a):** the full
  re-size (CROWN_RC 8→11, module 0.67→1.83, teeth 24/9→12/6, face 8). It ripples
  through ~15 coupled mesh constants (DRIVE_Z, PINION_TIP, CROWN_Z, the
  crown band radii…) with crown-ring-vs-sector-teeth clearance that **must be
  validated by CAD render** before shipping — so it is specified, not silently
  written, per the campaign rule.

### 2026-06 tooth-FORM upgrade (branch `feat/gearbox-linkage-redesign`)

The gearbox-polish pass replaced the **representative straight-flank** teeth with
**true involutes** where it matters, *without* re-sizing — so this whole FEA chain
stays valid as-is:

- **Spur sector pair (A_L↔A_R)** and the **input pinion** are now sampled-involute
  (25° pressure angle, 0.15 mm designed circular backlash, the 9-tooth pinion
  profile-shifted x=+0.25 + tip-truncated to clear undercut). Conjugate flanks roll
  instead of tip-gouging → the visible mesh ripple/backlash is gone.
- **CROWN_RC (8), PINION_RP (3), CROWN_TEETH (24), PINION_TEETH (9) are HELD**, so
  `CROWN_RC/PINION_RP = 24/9 = 8/3` is unchanged and **T_safe, the torque chain,
  slip margin and selection scores are untouched** (no campaign re-run). The pinion
  tip stays < the journal bore, so the one-piece input shaft still installs
  pinion-first — the reason the bigger D10-a re-module was *not* taken here.
- The **crown stays representative proud radial blocks** (now phase-locked to the
  involute pinion with `PINION_PHASE_DEG`, and pitch-plane-tangent via the new
  `DRIVE_Z`), deliberately kept block-form so the conservative straight-cantilever
  `gear_fea*.py` model still bounds it — the crown remains the binding link at
  **T_safe ≈ 0.013 N·m (radial)**. A fully conjugate face-gear crown is the open
  follow-on. Re-running `gear_fea*.py` on the involute pinion only *raises*
  `T_safe(pinion)` (stronger root), it does not move the binding crown bound.

## 6. The current-limit ceiling (the sensing-pivot connection)

T_safe **is** the firmware current-limit ceiling: the actuator is current-controlled
(the sensing pivot), so commanded torque must stay below T_safe. Achievable safe grip
`F_tip ≈ T_safe · i_g · MA · η / 2`:

| geometry | T_safe (2D, by which model) | safe grip per finger (band over η, MA) |
|---|---|---|
| shipped (single-station 2D) | 0.034 N·m | **0.35 – 0.73 N** |
| shipped (radial 2D inner edge)| **0.013 N·m** | **0.13 – 0.28 N** |
| proposed re-size (single-station) | 0.40 N·m | **4.2 – 8.7 N** |

So the **shipped representative geometry is a bench/integration article** (grip
≪ 1 N before crown-tooth yield); a **functional grip needs the re-size**
(~4–9 N), and even then the right-angle stage caps grip below the finger's 12 N
*stress-probe* capability (which is itself the FEA-comparison load, not an
operating force — see `docs/TESTING_AND_SIMULATION.md` A.8). The live force band
is regenerated by `motor/scripts/drivetrain_force_envelope.py`. *That is the
campaign finding*, not a number to bury.

## 7. Margin vs the selected servos — current limit is MANDATORY on both

The selected servos can *mechanically* exceed T_safe and destroy the gears on a
fault, so an ESC/firmware current limit is **required for both** (not just the strong
one):

| servo | stall torque | × shipped T_safe | × proposed T_safe |
|---|---|---|---|
| DYNAMIXEL XW540-T260 | 9.5 N·m | ~280× | ~12–24× |
| Feetech STS3250 | **4.9 N·m** | ~144× | ~12× |
| Feetech STS3215 | 2.94 N·m | ~86× | ~4–7× |

All three ≫ T_safe → **"one decision, three *ESC profiles*"**: same torque setpoint
(~0.5 N·m-class motor for a useful grip on the re-sized train), but each servo needs
its own current-limit configured to the same torque ceiling. (Resolution check for
`SENSING.md`: XW540 `present_current` 2.69 mA/step ≈ 0.005 N·m/step — a 0.05 N·m
ceiling is ~10 LSB of headroom: fine but tight; **STS3250 K_t ≈ 1.17 N·m/A** so a
0.05 N·m ceiling = ~43 mA, well inside the load-feedback proxy's resolution; the
STS3215's 6.5 mA/step is the tightest of the three.)

## 8. Why the fallback wins where this can't

The magnetic-coupling fallback (`SELECTION.md` D8) removes this bottleneck: its
**pole-slip torque scales with coupling diameter, not housing radius**, so a
60–80 mm coupling clears the stall band (KTR MINEX-S SA 60/8 = 7 N·m; an 80 mm N52
ring ≈ 6 N·m) with margin the cramped right-angle stage can never reach — and the
pole-slip *is* a mechanical force limiter (it protects the gripper and the specimen).
The gear FEA is the quantitative reason the fallback is a genuine #2, not a courtesy.

## 9. Self-similar scaling — T_safe ~ k³, tip force ~ k² (the gear is *still* the limit)

`gripper.py` now carries a global self-similar scale (`GRIPPER_SCALE`, default 1.0).
At `GRIPPER_SCALE = k` every linear gear dimension scales by `k` while the tooth
**counts are held**, so the module scales `k` and the mesh ratio `i_g = 24/9 =
2.667:1` is preserved (true mechanical similitude). All four chain scripts
(`gear_fea.py`, `gear_fea_radial.py`, `drivetrain_force_envelope.py`,
`kinematics_chain.py`) read `gripper.py` for their dims, so `GRIPPER_SCALE=k`
propagates automatically — no per-script parameter editing.

The power laws fall out of dimensional analysis and are confirmed numerically:

- **Tooth root-bending capacity `T_safe ~ k³`.** Allowable tooth force `F_allow ∝
  σ_allow · b · s_root² / h ∝ k²` (face width `b ~ k`, root thickness `s_root ~ k`,
  height `h ~ k`), and the lever (`PINION_RP ~ k`) adds one more `k` →
  `T_safe = F_allow · lever ~ k³`. σ_allow (material) is held.
- **Mechanical advantage `MA ~ 1/k`.** `MA = |dθ_crank/dx_P|`: the crank angle is
  similitude-invariant, the contact displacement `dx_P ~ k`, so `MA ~ 1/k`.
- **Deliverable tip force `F ~ k²`.** `F = T_safe · i_g · MA / 2 · η`, with `i_g`
  and `η` scale-invariant (counts + angles held) → `F ~ k³ · k⁻¹ = k²`.

Reproduce: `GRIPPER_SCALE=k PYTHONPATH=. python motor/scripts/gear_fea_radial.py`
(and `gear_fea.py`, `drivetrain_force_envelope.py`). Result JSONs per scale live in
`variants/scale_<k>x/fea/`; the combined summary is
`variants/scale_scaling_summary.json`.

### 9.1 Headline table (radial 2D inner-edge bound — the self-similar basis)

The **radial 2D crown FEA** (`gear_fea_radial.py`, the binding inner-edge slice) is
the scaling headline: it is fully geometry-driven from `gripper.py`, so it reads the
power law cleanly. The single-station 2D (`gear_fea.py`) independently confirms `k³`.

| `GRIPPER_SCALE` | `T_safe` (radial 2D) | `T_safe` (single-station 2D) | per-finger force band | T_safe ratio vs 1× | force-hi ratio vs 1× |
|---|---|---|---|---|---|
| **1.0×** | 0.0131 N·m | 0.034 N·m | **0.14 – 0.28 N** | 1.00 (k³ = 1.00) | 1.00 (k² = 1.00) |
| **1.5×** | 0.0442 N·m | 0.113 N·m | **0.31 – 0.64 N** | 3.37 (k³ = 3.375) | 2.25 (k² = 2.25) |
| **2.0×** | 0.1048 N·m | 0.268 N·m | **0.55 – 1.13 N** | 8.00 (k³ = 8.00) | 4.00 (k² = 4.00) |

The fits land on `k³` / `k²` to three significant figures. **`T_safe` and the force
band are quoted on the *same* radial 2D basis** — they are not mixed across models.

### 9.2 Servo headroom — the ratio SHRINKS with scale, but the gear is still the limit

`T_safe` grows as `k³` while servo stall torque is fixed (a bigger gripper does not
get a bigger motor for free), so the **stall ÷ T_safe ratio shrinks with scale**.
That ratio is *not* comfort headroom — it is the **over-torque danger**: how badly a
servo would smash the printed crown on a firmware/limit fault. Smaller is *safer* in
that sense, but it is still enormous:

| servo | stall | × T_safe @ 1.0× | × T_safe @ 1.5× | × T_safe @ 2.0× |
|---|---|---|---|---|
| DYNAMIXEL XW540-T260 | 9.5 N·m | ~725× | ~215× | ~91× |
| Feetech STS3250 | 4.9 N·m | ~374× | ~111× | ~47× |
| Feetech STS3215 | 2.94 N·m | ~224× | ~67× | ~28× |

Even at 2.0× the weakest servo in the ladder (STS3215) still over-torques the gear by
~28×; the crossover where a servo could *no longer* exceed `T_safe` is around `k ≈ 6`
(`T_safe ∝ k³` reaches ~2.94 N·m near `k = 0.0131·6³·...`, i.e. far beyond any
printable size). **Conclusion: the gripper is gear-limited at every scale in
[1.0, 2.0], and the firmware current-limit remains the mandatory gear-protection
mechanism at all scales** — the same "one decision, N ESC profiles" posture, just
with the per-scale `T_safe` setpoint from the table above. The force *grows* with
size (good — a 2× gripper delivers ~4× the per-finger clamp force, 0.55–1.13 N vs
0.14–0.28 N), but it is **still capped far below the finger's 12 N stress-probe
capability**, so the qualitative finding of §6 is scale-invariant: a *functional*
absolute grip still needs the module/radius re-size, not just a bigger envelope.

### 9.3 Honesty: what does NOT scale cleanly, and the high-fidelity follow-up

- **`gear_fea_3d.py` is NOT self-similar as configured.** It hardcodes `DISK_T =
  4.0 mm` (absolute, not `×SCALE`) and meshes at **absolute** gmsh sizes
  (`mesh_max=0.6, mesh_min=0.25`), so its mesh density (988 → 1567 → 2658 nodes) and
  its disk-to-tooth proportion both change with `k`. Its `T_safe` therefore reads
  0.0161 → 0.140 → 0.326 N·m, a ratio of ~8.7× / ~20× vs `k`, far above `k³`. This is
  a **tooling artifact, not physics** — the 3D model simply cannot read the power law
  while its disk and mesh are pinned to absolute sizes. The shipped 1× repo posture
  (per `docs/OVERNIGHT_FIXES.md`) treats 3D as the better *physics* at 1×; that judgement
  stands for the 1× point, but for the **scaling study the radial 2D bound is the
  honest basis** because it is the one that is actually self-similar. The 3D
  per-scale JSONs are retained in `variants/scale_<k>x/fea/_gear_fea_3d.json` flagged
  as non-scaling.
- **High-fidelity re-run warranted (follow-up):** make `gear_fea_3d.py`
  self-similar (`DISK_T = 4.0 * g.SCALE`; gmsh `MeshSizeMax/Min` scaled by `SCALE`)
  and re-run at `k ∈ {1.0, 1.5, 2.0}` on a GPU workstation (RTX 3070)
  to confirm the 3D solve also recovers `k³` once disk + mesh scale with the part.
  This is the clean way to cross-check the radial 2D headline at higher fidelity; it
  is left for the GPU workstation because the 3D mesh + build123d STEP step is the heavy part.
- **`torque_chain.py` does NOT scale.** Its `T_SAFE` and `SERVOS` are **hardcoded 1×
  literals** (lines 33–37); it only imports `kinematics_chain` for `MA`/`i_g`. Run at
  `GRIPPER_SCALE=k` it therefore pairs `k`-scaled `MA` (which falls as `1/k`) against
  *fixed* 1× `T_safe`, producing tip-force curves that **shrink** with scale — the
  exact opposite of the real `k²` law. It is a **1× illustration plotter only**; its
  scaled output must not be quoted. To make it scale you would replace the `T_SAFE`
  literals with the per-scale radial values from §9.1 (a one-line-per-scale edit, left
  optional since the force-envelope script already delivers the correct per-scale
  band).
- **All bounds remain 2D/linear upper-bound estimates.** Scaling does not change the
  §-Honesty caveats: straight-flank-vs-involute edge-loading, no base-disk compliance
  in 2D, no moving contact line. The bench torque-to-failure on a printed coupon
  (`BENCH_TEST.md`) is the only validated ceiling, at every scale.

> **Honesty.** T_safe is a 2D-FEA upper-bound estimate. The crown is a 3D face
> gear (a 2D plane-stress single-station tooth model is partial; the
> radial-station integration on this branch is tighter but still 2D), the
> teeth are "representative straight-flank" not involute (so they will
> edge-load and gall in PA12-GF rather than roll cleanly), and the
> base-disk bending compliance + moving contact line are not modelled. The
> shipped value reads "0.013 N·m (radial 2D) / 0.034 N·m (single-station 2D)"
> — both are conservative upper bounds, and the true ceiling is even lower.
> Bench torque-to-failure on a printed coupon is the validation
> (`BENCH_TEST.md`). Cross-links: `SELECTION.md`, `DECISION_LOG.md`,
> `SENSING.md`, `fea/DECISION_LOG.md`.

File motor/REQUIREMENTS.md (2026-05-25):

# Actuator requirements — derived from the gripper kinematics

What the user-supplied waterproof actuator must deliver at the bottom
**D-coupler** of `input_pinion_shaft`, derived from the *live* `gripper.py`
mechanism (not assumed). Torque / speed / stall / holding are given as a single
**band** (they barely move with depth); the **IP / seal / connector / voltage /
material** requirements are split into three depth tiers.

> **Primary design point: tier 2 — shallow seawater, ≤ 30 m.** Tiers 1 (≤ 10 m)
> and 3 (> 30 m) are carried through as sensitivity edges so the Phase-3 scoring
> visibly flips actuator class with depth. The mechanism is unchanged across
> tiers — the same D-coupler accepts a different actuator class per depth. That
> *is* the modular-product argument.

> **Honesty (carried from `grip/GRIP_MODEL.md`):** this is a **mechanics-based
> sizing**, not a calibrated absolute-newton prediction of the built tool. The
> torque↔force relation is exact kinematics from `gripper.py`; the **efficiency
> is an estimate band**, and the target clamp force is **anchored** on the
> finger-FEA report level, not measured on hardware. Numbers size and rank the
> actuator field; they are not a guarantee of grams-force at the fingertip. The
> bench-test plan (`BENCH_TEST.md`) is where absolute force gets measured.

> **Sensing pivot (campaign update).** The actuator is now also the gripper's
> **force sensor** — motor current → torque → drivetrain back-trace → tip force,
> the same principle used by force-controlled industrial/surgical grippers
> (Maxon, Robotiq, Schunk). This adds a **hard selection filter**: a candidate
> must stream torque/current telemetry fast and fine enough to resolve a
> sub-slip grip-force step (§8 below). It also removes the old conductive-foam
> fingertip sensor (zero fingertip electronics underwater — see `DECISION_LOG.md`).
> Sensed force is itself a **relative** signal unless calibrated against a load
> cell (`SENSING.md`), so the rank-only caveat carries over to the force readout.

All numbers below are reproduced by:

```bash
/home/andre/.cad-venv/bin/python motor/scripts/kinematics_chain.py
# -> prints the tables + writes motor/iterations/_requirements.json
```

---

## 1. The drive chain (read from `gripper.py`)

```
  ACTUATOR  ── D-coupler (Ø10, D-flat 1.4 mm, 12 mm engagement)
     │
     │  crown/pinion right-angle stage     i_g = CROWN_TEETH/PINION_TEETH = 24/9 = 2.667:1  (reduction)
     ▼
  LEFT sector gear  (crank A_L)
     │  spur mesh 1:1 to RIGHT sector gear (R_GEAR = 12 mm both)
     ▼            └─ so the LEFT gear carries BOTH fingers
  four-bar  (A→C crank 34, B→D follower 32, C→D coupler 20)  ×2, mirrored
     ▼
  fingertip / contact-face clamp force  F  (per finger)
```

**Quasi-static torque balance** (lossless, then de-rated by efficiency `η`):

- left-gear torque `T_L = T_motor · i_g`
- the 1:1 mesh makes the left gear drive both fingers → `T_L = 2 · T_finger`
- four-bar virtual work at a finger contact point P:
  `F · dx_P = T_finger · dθ_crank` → `MA(P) = F/T_finger = |dθ_crank/dx_P|`

$$\boxed{\,F = T_{motor}\cdot \tfrac{i_g}{2}\cdot MA(P)\cdot \eta \qquad\Rightarrow\qquad T_{motor} = \frac{F}{\tfrac{i_g}{2}\, MA(P)\, \eta}\,}$$

`MA(P)` is the four-bar Jacobian at point P, evaluated numerically on the live
solver. It is **largest near the finger base** (short moment arm) and
**smallest at the tip** — so the tip is the *sizing-conservative* point and the
contact-face centre is the *practical-use* point.

| Point on finger (clamp pose, open = 0) | MA `\|dθ/dx\|` (1/mm) |
|---|---|
| base of grip texture (0.15·L) | 0.0277 |
| **contact-face centre (0.55·L) — practical** | **0.0230** |
| tip of grip texture (0.95·L) | 0.0196 |
| blade tip, centreline (1.0·L) — **conservative** | **0.0192** |

---

## 2. Torque requirement (the binding constraint)

**Target clamp force band: 8 – 15 N per finger**, anchored on the **12 N**
"force-targeted reporting" level from the finger FEA (`fea/UNIVERSAL_FINGER.md`).
That 12 N is the *common basis chosen to compare finger designs fairly* — not a
physically-mandated load — and the FEA showed the finger carries it with ~10×
von-Mises margin, so it sits well inside structural capacity. 8 N is a soft/
slippery-object floor; 15 N is a firm-grip ceiling that still keeps the finger
and printed gears in their safe band (see `DRIVETRAIN.md` gear recheck).

**Efficiency envelope** (estimate — printed, flooded, largely unlubricated):

| Stage | η range | basis |
|---|---|---|
| crown/pinion right-angle mesh | 0.65 – 0.85 | printed straight-flank face mesh, dry/flooded |
| spur 1:1 mesh | 0.85 – 0.95 | printed spur, plastic-on-plastic |
| four-bar (2 loaded journal pivots/finger) | 0.80 – 0.90 | flooded plastic journals |
| input-shaft journals (×2) | 0.90 – 0.97 | flooded plastic plain bearings |
| **total** | **0.40 – 0.71** | product of stage bands |

**Required input-shaft torque** (mid-face/high-η best case … tip/low-η worst case):

| Clamp force / finger | Required input torque (N·m) | ideal @ tip (η=1) |
|---|---|---|
| 8 N | 0.37 … 0.78 | 0.31 |
| **12 N (FEA anchor)** | **0.56 … 1.18** | 0.47 |
| 15 N | 0.70 … 1.47 | 0.59 |

### Spec

| Quantity | Value | Rationale |
|---|---|---|
| **Continuous torque (target)** | **≥ 1.2 N·m** at the D-coupler | covers the worst case (tip, 12 N, η = 0.40) with margin; reaches 15 N at favourable contact points |
| Continuous torque (floor) | ≥ 0.6 N·m | below this, 12 N is unreachable even at the practical mid-face point |
| Continuous torque (desirable) | ≥ 1.5 N·m | headroom for 15 N at any contact point + the low-η edge |

These barely change with depth, so they are **one band across all three tiers**.

---

## 3. Speed & travel — *not* a binding constraint

A full open↔close is **only 122.7° of input rotation** (crank sweep 46° ×
i_g 2.667). So:

| Full-stroke time | Required input speed |
|---|---|
| 2.0 s (gentle) | 10.2 rpm (61°/s) |
| 1.0 s (nominal) | 20.4 rpm (123°/s) |
| 0.5 s (fast) | 40.9 rpm (245°/s) |

**Spec: ≥ ~20 rpm (≈ 123°/s) at the input, full travel ≤ ~123°.** Two
consequences that *shape the survey*:

1. The speed is trivial — any RC servo (60° in 0.1–0.2 s ⇒ 300–600°/s) clears
   it by ~3–5×, and even geared DC/stepper options reach it easily.
2. **A limited-rotation actuator is sufficient** — no continuous rotation is
   needed. This makes the **limited-arc waterproof hobby-servo class the natural
   primary** and lets *continuous-rotation drives be ruled out as overkill*
   (they'd need a position sensor + endstop logic the servo already has).

---

## 4. Stall & holding

- **Stall torque:** must exceed the continuous target (≥ 1.2 N·m) so grip can
  build without the actuator stalling short — but it must **not** be so high
  that an uncontrolled stall over-drives the fingers/printed gears. Target stall
  **1.5–3× continuous (≈ 1.8–3.6 N·m) with electronic torque/current limiting**
  to cap grip force. The compliant Fin-Ray finger and the geometric-capture
  joints tolerate modest overshoot, but force should still be *commanded*, not
  left to slam to stall (see `FAILURE_MODES.md`).
- **Holding:** the drivetrain ratio is low (2.667:1) and the four-bar has a
  healthy transmission angle, so the chain is expected to be **back-drivable** —
  the grip reaction pushes back to the input. Therefore the actuator must
  **hold position under the full grip reaction continuously** (a positional
  servo does this natively; a stepper holds with energised current; a brushed/
  BLDC needs a closed loop or a self-locking element). Holding torque ≈ working
  torque (0.6 – 1.2 N·m), continuous. *Back-drivability is confirmed numerically
  in Phase 5 (`holding_stall.py`).*
- **Duty:** grip-and-hold is intermittent in actuation but the **hold can be
  sustained for minutes** → the holding actuator's thermal duty (continuous
  stall-near current) is a real selection factor, analysed in
  `holding_stall.py` / `MOTOR_MODEL.md`.

---

## 5. Mechanical interface — the D-coupler (modularity boundary)

The actuator output must mate the existing coupler on `input_pinion_shaft`
(or be re-coupled — that re-coupling is the explicit modularity swap point):

| Coupler feature | Value (`gripper.py`) |
|---|---|
| Coupler radius `SHAFT_COUPLER_R` | 5.0 mm (Ø10) |
| D-flat depth `SHAFT_DFLAT` | 1.4 mm |
| Engagement length `SHAFT_COUPLER_LEN` | 12.0 mm |
| Axis | vertical, exits the housing bottom flange (world −Z) |
| Running env | flooded; printed PA12-GF shaft turns wet in two journal bores |

If a selected actuator's native output cannot drive this D-profile, the change
is proposed as a **numbered option in `DECISION_LOG.md`** and the gripper-side
coupler is *not* silently rewritten (per campaign rule). A printed adapter horn
that bridges actuator-spline → D-socket keeps the gripper untouched.

---

## 6. IP / seal / connector / voltage / material — by depth tier

Torque/speed/stall/holding above are constant; **these** are what move with
depth. Tier 2 is the primary design point.

| Aspect | Tier 1 — ≤ 10 m (bench / pool) | **Tier 2 — ≤ 30 m (PRIMARY)** | Tier 3 — > 30 m (subsea) |
|---|---|---|---|
| **IP / seal strategy** | IP68 hobby servo *or* epoxy-potted servo; static/grease-packed output OK | **Genuine IP68 submersible servo, or sealed body with a dynamic rotary shaft seal, or oil-filled servo** | Oil-filled / pressure-compensated actuator, or **magnetic coupling (no shaft penetration)** |
| **Shaft-seal type** | static / low-ΔP, grease | dynamic rotary lip/O-ring rated ≥ 3 bar (~30 m) | pressure-compensated (ΔP ≈ 0) or non-contact magnetic |
| **Connector class** | splash / IP67 (potted JST, Molex) | **wet-mateable or potted bulkhead ≥ 30 m** (SubConn micro / BlueTrail / DIY potted) | subsea wet-mate + pressure block (SubConn / Birns) |
| **Voltage budget** | 12 V (small-ROV 3S–4S battery) | **12 V nominal; 24 V acceptable**, tether ΔV budgeted | 24–48 V (lower current ⇒ less ΔV on a long tether) |
| **Housing / seal material** | PETG + nitrile O-ring | **ASA/PA-GF body; EPDM/nitrile seals; PTFE shaft seal** | PA-GF/POM + compensation oil (silicone/mineral); metal where ΔP demands |

---

## 7. ROV power-bus assumptions (stated, refined in `ELECTRICAL.md`)

- **Bus voltage: 12 V nominal** (BlueROV-class small-ROV convention) at the
  gripper, with **24 V** carried as a tier-3 option. The actuator must run from
  the available bus or via a dedicated regulator.
- **Peak current is the STALL current, not the run current.** Waterproof hobby
  servos stall at ~5–10× their continuous draw, so a 1.2–2 N·m-class servo at
  12 V can pull **~3–6 A on stall**. Budget the bus + fuse + tether conductor
  for the **stall**, not the average — otherwise the bus browns out the first
  time the gripper hits a hard object. Working budget: **≤ 6 A peak at 12 V** at
  the gripper, fused ~7.5–10 A, with inrush allowed for.
- **Signal:** a single PWM line (servo) is the baseline; CAN/UART/RS-485 are
  evaluated for sealed BLDC/stepper options in `ELECTRICAL.md`.

---

## 8. Force sensing through the actuator (the SoftSense pivot)

The actuator doubles as the grip-force sensor. The forward chain is the inverse
of §1: a measured motor current/torque telemetry sample is back-traced through
the same drivetrain to an estimated per-finger tip force:

$$\hat{F} = T_{sense}\cdot \tfrac{i_g}{2}\cdot MA(P)\cdot \eta \qquad\text{with}\qquad T_{sense}=K_t\,(I_{meas}-I_0)$$

(`SENSING.md` develops the forward + inverse models and the calibration; `MOTOR_MODEL.md`
carries the validation.) The selection-relevant budgets:

| # | Sensing requirement | Target | Basis |
|---|---|---|---|
| S1 | **Force resolution** (min detectable tip-force step) | **≤ 0.3 N** at the fingertip | ≈ 3 % of a 10 N working grip / 2 % of the 15 N ceiling (the FEA-anchored band). `grip_model.py` ranks textures' *relative* slip ordering — it is rank-only, so the **absolute** step target comes from the force band, not from absolute newtons it doesn't claim. |
| S2 | **Torque resolution at the input shaft** | **≈ 0.02 N·m** | S1 back-traced: 0.3 N ÷ (i_g/2 · MA_mid · η) at η≈0.5, MA_mid 0.023. Per-motor this is a current step ΔI = 0.02/K_t (evaluated per candidate in `SURVEY.md`). |
| S3 | **Telemetry rate** | **≥ 50 Hz** (desirable ≥ 100 Hz) | slip onset is detected on the force *derivative*; 50 Hz ⇒ 20 ms sampling resolves the contact/slip transient. |
| S4 | **End-to-end latency** (sense → controller → ROV topside) | **≤ ~50 ms** | usable closed-loop / operator grip control. Budget: ≤ 10 ms motor-side sense+filter, ≥ 40 ms for tether + parsing. |
| S5 | **Noise floor** | post-filter torque-sense noise < S2 (≈ 0.02 N·m RMS) | so the 0.3 N step is not buried. Brushed-DC commutation/PWM ripple (~5 %) exceeds this raw → needs filtering, which spends part of the S4 latency budget. |

**What this rules in and out** (full detail + citations in `SURVEY.md`):

- **In (native telemetry):** smart serial-bus servos expose `present_current`
  (Dynamixel X 2.69 mA/unit ⇒ ~0.005 N·m at the servo; Feetech 6.5 mA/unit) and
  FOC controllers expose `iq`/`torque` (moteus int32 ⇒ 1 mA / 1 mN·m). Both clear
  S1–S3 with margin and, crucially, **hold a clean torque estimate at stall** —
  the grip-and-hold state.
- **Out (no telemetry):** open-loop PWM servos (most IP-rated RC servos: Savox SW,
  Hitec WP, Traxxas) have **no current readback** → they cannot sense and are
  **DEAD** for this design, kept in `SURVEY.md` only with a one-line elimination.
- **Fallback-only:** sensorless BLDC back-EMF estimators go **blind below ~10–20 %
  rated speed** — i.e. at stall, exactly when grip force matters — so they are
  contact/stall *detection* only, never the primary force readout.
- **Ground truth:** a bench load cell (`SENSING.md`/`BENCH_TEST.md`) calibrates
  the current→force curve; an *in-situ* strain gauge is **not** re-introduced
  (it would put wiring back through the TPU — the very thing the foam removal
  avoided).

## 9. Requirement summary (the card the survey scores against)

| # | Requirement | Value |
|---|---|---|
| R1 | Continuous input torque | **≥ 1.2 N·m** (floor 0.6, desirable 1.5) |
| R2 | Stall torque | 1.8 – 3.6 N·m, with torque/current limiting |
| R3 | Input speed | ≥ ~20 rpm (123°/s); full stroke 0.5–2 s |
| R4 | Travel | limited rotation OK, full stroke ≤ ~123° |
| R5 | Holding | hold working torque continuously (back-drivable chain) |
| R6 | Interface | drive the Ø10 / 1.4 mm D-flat / 12 mm coupler (or adapter) |
| R7 | IP / depth | tier-2 ≤ 30 m primary; tiers 1 & 3 as edges (table §6) |
| R8 | Power | 12 V nominal; budget ~6 A peak (stall); single-PWM baseline |
| R9 | Material/seawater | hydrolysis-stable, galvanic-isolated at the M4 flange (`UNDERWATER.md`) |
| **R10** | **Force sensing via the actuator** | **stream torque/current telemetry: ≥ 0.3 N tip resolution (≈ 0.02 N·m input), ≥ 50 Hz, ≤ 50 ms latency (S1–S5)** |

`SURVEY.md` scores every candidate against R1–R10, tags which depth tiers (R7)
it satisfies, and adds the four sensing columns (modality / rate / protocol /
force-resolution); candidates that cannot sense (R10) are kept but tagged DEAD.
`SELECTION.md` weights them — **sensing fidelity is now a primary weighted axis
alongside torque, depth-tier fit and modularity** — and sweeps the weights ±50 %
(including depth tier) to pick a tier-2 primary + a fallback.

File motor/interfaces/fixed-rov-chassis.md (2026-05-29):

# Fixed-mount on ROV chassis — interface study

Adapter-mount research for **bolting the all-polymer flooded gripper directly to
an ROV chassis** (no manipulator arm in between). The ROV positions the gripper
with its own thrust; the gripper is a fixed forward- or downward-facing tool.

This is the inverse of the manipulator interface campaign (`motor/interfaces/`
arm-side files): instead of a Reach/Schilling end-effector plate, the gripper's
bottom M4 flange mates to a printed adapter that bolts to **chassis holes the
ROV vendor publishes**. Chassis-mount is the dominant pattern in hobby,
inspection-class, and citizen-science ROVs because manipulator arms cost more
than the vehicle they hang off.

> **Honesty.** Where Blue Robotics publishes a number (datasheet, store page,
> drilling-template PDF, or assembly guide) it is quoted verbatim with a
> numbered source. Numbers we could not verify (e.g. the often-repeated claim
> that BR2 side panels carry a 25 mm M3 grid) are surfaced in §11, not asserted.
> Estimates are marked **(estimate)**. The shipped manipulator-mount
> counterpart is `../ROV_INTEGRATION.md`; this file is the **chassis-mount**
> sibling.

---

## 1. Why a fixed chassis mount

Most published gripper-on-ROV integrations in the public hobby/conservation
literature use **chassis mounts, not arms.** The reason is price-class:

- **Manipulator arms** (Reach Bravo, Schilling Titan, ECA ARM 5E) start at
  USD ~10 k and target work-class vehicles. Reach Bravo's payload interface
  is a real product [12], but the arm itself dwarfs a USD-3 k BlueROV2.
- **Chassis grippers** (Blue Robotics Newton, Chasing Grabber Arm, QYSEA tool
  port) are USD 60–800. They bolt to the vehicle frame and the **pilot drives
  the ROV** onto the target.

Public reference applications all use the chassis-mount pattern:

| Application | Vehicle class | Gripper interface | Source |
|---|---|---|---|
| Lionfish removal (community & RSE prototypes) | BlueROV2 | Newton, or custom spear/suction on a chassis-bolted frame | [8] [13] |
| BR-promoted "autonomous lionfish harvester" | BlueROV2 | Newton, bottom-panel mount | [8] |
| BR product page — "for BlueROV2 and other ROVs" | BlueROV2 + 3rd-party | Newton bracket with 2× M5×16 | [2] [3] |
| Citizen-science conservation volunteer work | Mixed inspection-class | Chassis-mount tooling on hobby ROVs | [13] |
| Chasing M2 Pro recreational grab tasks | Chasing M2 family | Chasing Grabber Arm 2, P/N 121129 bracket | [9] |
| QYSEA V6 / V-EVO sampling | FIFISH inspection-class | "Robotic Arm Mount Kit" with 2 holders | [10] [11] |

The shared geometry: **gripper bolts under or in front of the vehicle's
camera, cable runs along the frame to the main electronics bottle, and the ROV's
thrusters do all the fine positioning.** No joint angles, no kinematics — just
two M-class screws and a cable.

For our gripper specifically, this is the natural fit for **T1 (≤10 m,
inspection)** and **T2 (≤30 m, primary)** depth tiers (`SELECTION.md`),
because hobby ROVs in that class do not carry manipulators. The XW540-T260
+ Blue Robotics 3" canister stack fits the BR2 payload skid envelope and uses
the same M3/M4/M5 fastener family BR ships everything in.

---

## 2. Reference ROVs — chassis interfaces per vehicle

| ROV | Chassis material | Published accessory interface | Documented gripper mount | Pub. payload budget | Notes |
|---|---|---|---|---|---|
| **Blue Robotics BlueROV2** (R3 / R4) | HDPE 1/2" (bottom + centre), HDPE 3/8" (sides); AL6061-T6 enclosure cradles [1] [4] | Bottom panel = blank HDPE drilled per template; Roof Rack accessory with pre-drilled multi-tool holes [6] [7] | **Newton Subsea Gripper** — 2× M5×16, drilled per BR drilling template [2] [3] | ~+0.2 kg net buoyancy with stock ballast; +0.5 kg additional from upgraded foam [1] [5] | The canonical hobby ROV; >50 % of public chassis-mount gripper builds |
| **BlueROV2 Heavy** | Same frame + extra horizontal thrusters | Same as BR2 + Heavy thruster brackets | Same as BR2 | Same payload class | Vector-thrust 6-DoF; gripper mount unchanged from BR2 |
| **BR2 Payload Skid** (BR-100233) | HDPE 1/2"; AL6061-T6 mounting clips [14] | 8× M5×16 to clamp under BR2; 4× M5×20 panels-to-bottom; 12 ballast-weight slots | Newton can mount to skid bottom panel (same 2× M5 footprint) | 12× 200 g extra ballast slots ⇒ 2.4 kg ballast budget if foam upgraded | Skid is 475 × 338 × 197 mm, 1200 g in air [14] |
| **OpenROV Trident** (discontinued, but still in field) | Moulded ABS shell, 410 × 205 × 86 mm, 3.5 kg [15] | "Payload Interface" rear bay, dimensions un-published in Kickstarter update [16] | Community 3D-printed claw grippers (rubber-band actuated) [17] | Not published | Forum/Kickstarter only; no formal accessory ecosystem since OpenROV shutdown |
| **Chasing M2 / M2 Pro / M2 Pro Max** | Moulded plastic shell + 1/4-20 tripod + proprietary accessory rail | Vendor-only "Mounting Bracket" P/N **121129** (required for M2 Pro Max) [9] | Vendor **Grabber Arm 2** (7 kgf, 170 mm range, 2.8 s actuation, 100 m depth) — only mount path | Not published | No public bracket drawings; vendor-locked |
| **QYSEA FIFISH V6S / V6 EXPERT / V-EVO** | Moulded plastic + vendor accessory port | "Robotic Arm Mount Kit" = 1 arm mount + 2 holders [10] [11] | Vendor 1-DoF claw arm; tool head swaps (clamp / sampler / circular claw) | Not published | "Over 20 professional tools" all share one undocumented bay [11] |
| **Custom T-slot ROV (DIY hobby)** | 20 × 20 mm aluminium extrusion, V-slot or T-slot | M5 T-nut + M5 button-head every 20 mm; any face, any orientation | DIY only — community examples vary | Builder-defined | Our printed adapter only needs 2× M5 T-nut holes spaced on any 20 mm multiple |

Take-aways:

- **BR2 is the only ROV in this class with public dimensioned mounting docs.**
  Everyone else is vendor-locked (Chasing, QYSEA) or community/discontinued
  (Trident). The mount design therefore *anchors on BR2*, and we describe the
  others as compatibility notes.
- **The Newton bracket footprint (2× M5×16 on a 100 mm-pitch line, 16° tilt)
  is the de-facto BR2 chassis-mount standard** — and the cheapest single
  interface for any third-party gripper to copy.

---

## 3. BlueROV2 — chassis geometry we could verify

### 3a. Top-level dimensions

| Quantity | Value | Source |
|---|---|---|
| External length | 457 mm (18 in) | BR datasheet/specs [1] |
| External width | 338 mm (13.3 in) | [1] |
| External height | 254 mm (10 in) | [1] |
| Weight in air, no ballast | 9–10 kg (20–22 lb) | [1] |
| Weight in air, with ballast | 10–11 kg (22–24 lb) | [1] |
| Net buoyancy, no ballast | +1.4 kg (+3 lb) | [1] |
| Net buoyancy, with ballast | +0.2 kg (+0.5 lb) | [1] |
| Max rated depth | 100 m (330 ft) | [1] |
| Max tested depth | 130 m (425 ft) | [1] |
| Stock ballast | 6 × 200 g coated lead | [1] |
| Main tube ID × L | 102 × 298 mm (4.0 × 11.75 in) | [1] |

**Why this matters for our gripper.** A standard BR2 (no foam upgrade) has
+1.4 kg net positive buoyancy *without* ballast. After the ~1.2 kg of stock
ballast it's near-neutral. Our gripper stack (≤350 g gripper + ~600 g BR 3"
canister assembly with XW540 + cable; *estimate*, see §6) consumes
**~0.95 kg of the standard ballast budget if we remove ballast to compensate**
— which is the natural integration path: take out 5× 200 g lead, add 950 g
gripper, you're back to ~+0.2 kg net buoyancy.

### 3b. Frame composition (R3 / R4) [4] [18]

| Panel | Material | Thickness | Quantity | Attachment |
|---|---|---|---|---|
| Side panels | Black HDPE | 3/8" (9.5 mm) | 2 | M5×20 to bottom panel (4×); M5×16 to centre panels (8×) [18] |
| Bottom panel | Black HDPE | 1/2" (12.7 mm) | 1 | Foundation for battery + skid mount |
| Front/rear centre panels | Black HDPE | 1/2" (12.7 mm) | 2 + 2 | Rear has 3 large pass-throughs |
| Enclosure cradle (4" series) | AL6061-T6, type III anodized | n/a | 2 | M4×18 to centre panels (8×) |
| Battery clamp (3" series) | AL6061-T6 | n/a | 1 | M4×14 to bottom panel (4×) |
| Stock-bag fasteners | 316 stainless | mixed M3/M4/M5 | as above | All metal hardware 316 SS [4] |

**No factory accessory grid is published.** BR ships the bottom panel as a
**blank HDPE plate** that the customer drills per the printed template that
comes with each Newton Gripper (§4). The Roof Rack accessory carries
pre-drilled multi-tool holes (§3d), but the **side and bottom panels do not.**

### 3c. Bottom panel — the canonical gripper-mount surface

From the Newton drilling-template PDF (BR document
`NEWTON-GRIPPER-W-MOUNTHOLE-DRILLING-TEMPLATE-R1`, SolidWorks 2018) [3]:

- Newton's bracket sits on the **underside of the bottom panel**, with the
  counterbore side facing **down**.
- Two M5 clearance holes are drilled **through the full 12.7 mm HDPE thickness**.
- The drill bit is **Ø5.50 mm** (or 7/32") — that's M5 clearance with thread
  rolled directly into HDPE (no metal insert).
- The two holes lie on a line **100 mm pitch**, with offsets **16 mm** and
  **31 mm** from a reference edge (right vs. left side respectively), at a
  **16° angle** to that edge.

> **The 16° tilt is the design insight.** The bottom-panel Newton mount is not
> orthogonal to the keel — it's canted ~16° so the gripper jaws clear the
> bottom panel and aim into the front-camera frustum. Any third-party gripper
> intending to drop into "the Newton mount slot" must inherit this tilt or
> publish its own offset.

| Newton-mount drilled-hole geometry (BR template R1) | Value |
|---|---|
| Hole count | 2 |
| Hole diameter | Ø5.50 mm (or 7/32") |
| Hole pitch (between centres) | 100 mm |
| Right-side edge offset | 16 mm |
| Left-side edge offset | 31 mm |
| Pattern angle to side edge | 16° |
| Drill direction | Straight through HDPE bottom panel |
| Fastener | 2× M5×16 button-head socket cap [2] |

### 3d. Roof Rack — the alternative front-mount surface

BR-200126 / "BlueROV2 Roof Rack" [6] [7]:

- Material: AL 5052-H34 (bent sheet).
- Mass: 177 g in air [6].
- Cost: USD 57 [6].
- Mount to BR2: **uses existing mounting holes** on the side panels (top
  mount), or the four Lumen-light holes (front mount) [7].
- Top-mount fasteners (included): 4× M5×12 button-head [7].
- Front-mount fasteners (included): 4× M3×12 socket-head [7].
- Pre-drilled hole sets on the rack itself (from BR): WTE3 + WTE4 clamps (×3),
  Lumen lights (×4), Ping360 (×3), **Newton Gripper (×2)**, Sonoptix Echo (×3),
  1/4-20 UNC tripod mounts (×3) [6].
- Two top-mount angles available: **0° (flat)** or **10° tilt**, by choosing
  different bolt hole pairs on the rack [7].

> **Hole coordinates not published.** The Roof Rack drawing referenced on the
> store page does not give per-feature coordinates we could parse. BR's
> documented design intent is "every supported accessory has 2–4 holes
> pre-drilled in known positions, use the installation guide for that
> accessory" [7] — but those guides do not redistribute the per-coordinate
> data either. **For our adapter, this means we either (a) carry our own M5
> pattern matching Newton's 2-hole footprint and use the rack-Newton positions,
> or (b) buy a Roof Rack, photogrammetry-measure it, and design to the measured
> dimensions.**

### 3e. Payload Skid — third mount surface

BR-100233 (BR2 Payload Skid) [14] [19]:

| Quantity | Value | Source |
|---|---|---|
| Length × width × height | 475 × 338 × 197 mm | [14] |
| Mass in air | 1200 g (2.65 lb) | [14] |
| Panel material | HDPE (sides, bottom); AL6061-T6 (mounting clips) | [14] |
| Attach to BR2 (mounting clips) | 8× M5×16 button-head [19] | [19] |
| Frame internal fasteners | 4× M5×20 (panels-to-bottom); 4× M4×14 (clamps); 4× M3×12 (enclosure clamp) | [19] |
| Ballast slots | 12× 200 g positions (= 2400 g compensation budget) | [14] |
| Payload bays | 2× 4" enclosures **or** 3× 3" enclosures + 2× Lumens | [14] |
| Cost | USD 320 | [14] |

A BR2 Payload Skid is **the cleanest production path for our 3" canister
gripper** because it natively accommodates a 3" enclosure clamped on its
underside *and* a Newton mount on the same bottom panel. The skid mounting
clips bolt to the same side-panel holes the Roof Rack uses [14].

---

## 4. Newton Subsea Gripper — the canonical chassis-mount gripper

The Newton Gripper is the de-facto reference because it is **the only mass-
market chassis-mount gripper with a publicly dimensioned BR2 mount.** Everything
about our adapter should at minimum be Newton-compatible at the chassis side,
because that lets us slot into the existing BR2 ecosystem with zero new holes.

### 4a. Published specs (BR product page) [2]

| Quantity | Value |
|---|---|
| SKU | BR-100789 (current R2-RP); also seen as BR-100862 in older listings |
| Cost | USD 720 |
| Supply voltage | 9–18 V |
| PWM logic voltage | 3.3–5 V |
| Peak current | 6 A |
| PWM neutral | 1500 µs |
| PWM open | 1530–1900 µs |
| PWM close | 1100–1470 µs |
| Grip force, jaw tip | 97 N (22 lbf) |
| Grip force, mid-jaw | 124 N (28 lbf) |
| Jaw opening | 62 mm (2.44 in) |
| Linear travel | 13.5 mm (0.53 in) |
| Operation time, open → close | 1.6 s |
| Length, closed | 303.2 mm (11.94 in) |
| Length, open | 309.2 mm (12.17 in) |
| Body diameter | 36 mm (1.42 in) |
| Mass in air | 524 g (18.5 oz) |
| Mass in water | 267 g (9.4 oz) |
| Housing | Aluminium 6061-T6 (anodized) |
| Pressure rating | 300 m (984 ft) |
| Cable | BR-101050 (3 conductors, 22 AWG, 635 mm length) |
| Wiring | Black GND, red +V, yellow PWM signal |
| Device-side penetrator | M06-4.5mm-LC |
| Cable-end penetrator | M10-4.5mm-LC |
| Mount kit | Anodized AL bracket + thumbscrew + 2× M5×16 + M10 nut/O-ring |

### 4b. Mounting kit contents (BR install guide) [3]

- **Mount kit (included in BR-100789):** anodized aluminium clamp bracket
  with thumbscrew, 2× M5×16 button-head, M10 penetrator nut + O-ring.
- **Additional hardware required:** medium-strength threadlocker; 3 mm hex
  driver; **5.50 mm drill bit (or 7/32")**; tape; printed drilling template
  (PDF, BR website).
- **Penetrator on BR2 end:** drilled into a blank position on the 4" end cap
  using the M10 hole — the gripper's signal/power cable runs through this and
  terminates inside the electronics enclosure.

### 4c. BR2 install procedure summary [3]

1. Power off; remove enclosure mounting screws (M3, 2.5 mm hex).
2. Slide enclosure aft, expose end cap.
3. Remove one of the **blank M10 penetrators** in the middle of the BR2 end
   cap with an M10 wrench.
4. Install Newton's M10 penetrator (lubricate O-ring with silicone grease).
5. Route signal wire to a Pixhawk PWM output channel; connect +V/GND to the
   terminal blocks inside the enclosure.
6. Reassemble enclosure (silicone grease on all O-rings).
7. **Print the Newton drilling template PDF at "Actual size,"** cut it out,
   tape it to the *underside* of the bottom HDPE panel (counter-bore side).
8. Drill 2× holes straight through with a Ø5.50 mm bit (hand drill OK on
   12.7 mm HDPE).
9. Weave the gripper through the frame from the front, clamp into the
   bracket, install 2× M5×16 from above with threadlocker.
10. Cable-tie the gripper cable along the frame to prevent thruster contact.
11. Rebalance ballast (typically remove 2–3 lead weights to compensate).

### 4d. Newton bracket dimensions — what BR does **not** publish

The Newton bracket is a custom anodized AL part. BR does not publish:

- Bracket outer dimensions (length, width, thickness).
- The bracket's relationship to the gripper's body cylinder axis (other
  than "two M5 clearance holes 100 mm apart, 16° canted").
- The thumbscrew torque spec.
- Bracket mass alone (the 524 g figure is the whole assembly).

**Verifiable inference (estimate, marked):** From the published 303 mm body
length and 36 mm body diameter, and the 100 mm 2× M5 footprint, the bracket
is ≥100 mm along the body and clamps a Ø36 cylinder — i.e. a saddle/clamp
geometry, not a flange. Our gripper, by contrast, has a planar flange at the
bottom of a 3" (76 mm) canister, so our adapter is a **flange-to-2× M5
pattern** transformer, not a saddle.

### 4e. Roof Rack front-mount (the second canonical Newton position) [6] [7]

The Roof Rack has *pre-drilled* "Newton (×2)" holes — Newton can move from
its bottom-panel slot to the Roof Rack without drilling. The Roof Rack itself
attaches to the BR2 in one of three positions:

- **Top, level (0°)** — over the electronics enclosure, between the
  side panels.
- **Top, 10° forward tilt** — same location, alternate bolt holes.
- **Front, inverted** — bolted to the four Lumen-light mounting points using
  4× M3×12.

The Newton on the rack faces **forward-down** when the rack is in the
front-mount Lumen-light position [7]. This is the second of the two
BR-blessed Newton geometries.

---

## 5. Forward vs downward vs side mount — trade-offs

| Aspect | Forward mount (nose) | Downward mount (belly) | Side mount (port/stbd) |
|---|---|---|---|
| Driving model | Pilot drives ROV forward into target | Pilot descends onto target | Lateral creep (used in pairs) |
| Visible in main camera | Yes — gripper appears in lower-front of frame | Marginal — needs lower-vehicle camera or angled main cam | Out of frame; pilot infers position |
| Centre-of-mass effect | Nose-heavy → trim nose-down (~5–10° pitch *estimate*) | Centred; lowers VCG slightly (good for roll stability) | Asymmetric → list angle |
| Bow-impact load | Yes — gripper takes initial chassis-tap | Low — descends onto target slowly | Low |
| Cable run to electronics tube | ~150–250 mm along top/side rails *estimate* | ~50–100 mm direct *estimate* | ~150 mm |
| BR2 implementation | Roof Rack front-mount (M3×12) or Newton on rack | Newton bottom-panel mount (M5×16, 16° tilt) | No supported BR2 path; custom only |
| Our gripper jaw direction | Jaws in line with ROV +X (push-grab) | Jaws point down (descend-grab) | Jaws point ±Y |
| Tasks suited | Spear-style grabs, lionfish, tether-attach, snag-clear | Bottom samples, archaeology, debris off seabed | Bimanual paired sampling (rare) |
| Trim compensation | Move ballast aft, add nose foam *(see §6)* | Symmetric — only mass-budget compensation needed | Counter-mass on opposite side |
| Failure-mode-on-impact | Gripper bracket and bottom panel take load | Gripper takes vertical impact only on descent | Skew load — worst for fasteners |

**Recommendation for our gripper** (`SELECTION.md` primary use case T2, BR2-class):

- **Forward (Roof Rack) is the recommended primary** because the gripper
  shows up in the main camera frustum without any extra camera hardware, and
  the lionfish/inspection use cases match the "drive into target" model.
- **Belly (Newton-bottom-pattern) is the recommended secondary** for sample
  collection / archaeology.
- **Side mount is out of scope** — no BR2-blessed path and our gripper is
  not designed for bimanual.

---

## 6. Trim / buoyancy implications for our gripper

### 6a. Mass budget (estimate, see `../REQUIREMENTS.md §1`)

| Component | Mass in air (g) | Notes |
|---|---|---|
| Gripper (all-polymer, flooded) | ~250–350 *(estimate; live `gripper.py`)* | Flooded ⇒ submerged mass ≈ 0 in seawater (PA12-GF SG ≈ 1.04; offset by water displacement) |
| BR 3" canister tube (240 mm, BR-102649-240) | ~250 *(estimate from BR product page)* | Aluminium |
| BR 3" end cap, penetrator face | ~120 *(estimate)* | Aluminium |
| BR 3" end cap, blank, drilled for shaft seal | ~120 *(estimate)* | Aluminium |
| XW540-T260 servo | 165 *(Robotis datasheet)* | |
| Internal mounting + cable gland | ~50 *(estimate)* | |
| Cable (RS-485 + power), 0.5 m to electronics bottle | ~30 *(estimate)* | |
| **Stack total in air** | **~985 g** *(estimate)* | Within ±15 % |
| **Stack net buoyancy in seawater (estimate)** | **+50 to +150 g positive** | Aluminium SG 2.7 dominates; tube is mostly air-filled → buoyant. **(estimate)** |

> **Why the net is *positive* in water.** The 3" canister is air-filled
> (servo dry inside), and its enclosed volume of ~2.0 L provides ~2.0 kgf of
> buoyancy *(estimate, π × 51² × 240 mm³)*. That largely cancels the ~1.5 kgf
> dry mass. The gripper itself is essentially neutral when flooded. We
> therefore expect a **net positive buoyancy of ~50–150 g** for the whole
> stack — i.e. we will be **adding lift, not lead, at the mount point**.

### 6b. BR2 ballast bookkeeping

| BR2 state | Net buoyancy (kg) | Source |
|---|---|---|
| As shipped, no foam, with ballast | +0.2 | [1] |
| Stock ballast removed entirely | +1.4 | [1] |
| With upgraded machined foam (R3 default) | +0.7 *(=+0.2 + 0.5)* | [5] |
| **Plus our gripper stack at ~+0.1 kg lift** | **+0.3 to +0.8 *(estimate)*** | derived |

**Compensation strategy (BR2 with stock foam):**

1. Remove **2× 200 g lead** from the rear ballast positions on the bottom
   panel to compensate for the gripper's mass *and* take advantage of the
   gripper's mild buoyancy. This biases pitch nose-down by ~3–6°
   *(estimate)*, useful for a forward-facing Roof-Rack-mounted gripper that
   wants to point into a target slightly below the horizon.
2. **Forward mount only:** add a 100 g foam wedge above the cradle to raise
   the COB *(centre of buoyancy)* over the new COM. (Optional; only
   noticeable in surge.)
3. **Belly mount only:** ballast remains roughly symmetric — only mass-
   budget compensation needed.

### 6c. Heavy-payload limit

The BR2 Payload Skid carries 12× 200 g extra ballast slots ⇒ **2400 g
compensation budget** [14]. Our ~1 kg stack consumes ~40 % of this. The
BR2 + skid + our gripper still has ample reserve for the upgraded foam
(+500 g lift) plus any other accessories. No buoyancy headroom problem at
T1/T2 depths.

---

## 7. Cable routing — bulkhead penetrator into the main electronics tube

### 7a. From canister to BR2 electronics enclosure

| Element | Spec | Source |
|---|---|---|
| Gripper canister cable exit | BR 3" end-cap blank penetrator (M10-4.5mm-LC or M10-7.5mm-LC depending on outer cable Ø) | BR penetrator catalogue [20] |
| Cable type | RS-485 + 12 V power, ≥4-conductor; 22–24 AWG signal, 18–20 AWG power *(estimate; see `../ELECTRICAL.md`)* | derived |
| Cable length, canister → electronics tube | 150–250 mm for forward (Roof Rack) mount; 80–150 mm for belly (bottom-panel) mount *(estimate)* | derived |
| Strain relief | Cable tie within 30 mm of each penetrator, plus 1× cable tie on the frame mid-run | BR ROV_INTEGRATION pattern, mirrors `../ROV_INTEGRATION.md §2` |
| BR2 enclosure entry penetrator | Re-use a blank slot on the BR2 end cap (the BR2 ships with 14× M10 slots, only some populated) | [1] |
| BR2-side connector | Same M10-4.5mm-LC blanks BR uses for thrusters and Newton itself | [3] |
| Service loop | ≥ 60 mm slack at the canister side and ≥ 30 mm at the BR2 side *(estimate)* | conservative |

### 7b. Why we don't need a separate wet-mate

BR's published flow is that the Newton (and our gripper by analogy) **goes
through a WetLink-style cable-end penetrator directly into the existing main
electronics enclosure** — no separate connector. The cable lands on
**screw terminals inside the enclosure**, next to the Pixhawk/Navigator
[3]. For RS-485 instead of PWM, the same end-cap penetrator path works; we
just terminate on the Navigator's serial header instead of a Pixhawk PWM
output (see `../ELECTRICAL.md`).

> **WetLink vs. SubConn.** BR's stock penetrator is a compression-gland WetLink
> (≤950 m rated [20]), assembled per-cable, not a wet-mateable connector.
> Pulling the gripper off the ROV in the field means **cutting cable ties
> and removing the end cap**, not unplugging anything. For T2 operations
> this is acceptable. For frequent swaps (T3 / professional), upgrade to a
> SubConn MCBH/MCIL micro circular connector on the BR2 end cap — adds
> ~USD 200 but allows wet-mate swap. Out of scope for the primary mount
> design.

### 7c. Cable abrasion protection along the frame

Same recipe as `../ROV_INTEGRATION.md §2a`:

- **Polyurethane spiral wrap or braided HDPE conduit** over the exposed run.
- Avoid PVC sleeving (embrittles in cold seawater).
- Cable ties every ~30 mm before any moving region; the BR2 has no moving
  parts in the cable path so the ties are pure abrasion control.

---

## 8. Vibration / impact protection — compliance bracket

Chassis-mount is **rigid** — the ROV's thrusters drive vibration straight
into the bracket, and any chassis-tap (driving the nose into a target)
delivers an impulse the bracket must accept.

### 8a. Vibration sources

| Source | Frequency band (estimate) | Mechanism |
|---|---|---|
| T200 thruster blade-pass | ~30–150 Hz at typical 1500–3000 rpm × 3 blades | Vortex shedding into chassis water |
| Servo gear meshing | ~10–40 Hz at 60 rpm output × tooth count | Gear FEA in `../DRIVETRAIN.md` shows gear ceiling is structural — minimise impulse from outside |
| Tether tug / surge | <1 Hz | Quasi-static; not a vibration concern |

### 8b. Recommended isolation stack

For a forward-facing Roof Rack mount, the gripper is ~150 mm forward of the
BR2 centreline and acts as a cantilever — vibration amplification is real.
Stacked from chassis up:

| Layer | Element | Function |
|---|---|---|
| 1 (under bracket head) | M5 nylon flat washer, 1 mm | Galvanic isolation + small compliance |
| 2 (bracket-to-rack interface) | **3 mm laser-cut TPU 95A compliance pad** (printed in-house from the same Bambu TPU 95A HF reel as the Fin-Ray fingers) | Vibration absorber + impact damper |
| 3 (rack-to-frame interface) | Rubber grommet sleeve isolator in each M5 hole *(McMaster 90131A132 family or eq.)* | Decouples high-frequency thruster vibration |
| 4 (M5 fastener) | A4-316 SS M5×20 with Loctite 243 *(not 271; medium-strength only)* | Per `../ROV_INTEGRATION.md §1c` |

The **TPU compliance pad** is the key idea. It is the same material we already
print the fingers in (Bambu TPU 95A HF), so no new BOM line. Sized to the
bracket's 2× M5 footprint plus 5 mm border, it transmits the static
clamp load (1.5 N·m × 1 mm thread pitch ⇒ ~9.4 kN per bolt; nylon-on-TPU is
fine) while absorbing ≥3 mm of impact travel.

### 8c. Impact / chassis-tap load

For a 9 kg BR2 driving forward at 1 m/s [1] into a stationary target,
the worst-case impulse if the gripper takes the full hit:

- Kinetic energy = ½ × 9 × 1² = 4.5 J.
- If stopping distance is 5 mm (rigid HDPE on rock), peak force ≈ 4.5 J ÷
  5 mm = 900 N (= 90 kgf). *(estimate, rigid-stop upper bound)*
- The 2× M5 SS A4 bolts have ≥4 kN shear capacity each — well above the
  impact load — but the **HDPE bore is the limiting element.** HDPE
  bearing strength ~25 MPa × 5.5 mm × 12.7 mm = 1.7 kN per bolt — also
  adequate, with a 1.8× margin.
- The TPU compliance pad reduces peak force by ~50–70 % by lengthening the
  stop distance from 5 mm to 15–20 mm. **Strongly recommended for any
  forward-mount build.**

> **`../FAILURE_MODES.md`** covers downstream failure paths (gear cracking,
> servo stall); the chassis mount adds one new mode — **HDPE bore wallowing**
> under repeated impact. Inspect the 2× M5 holes after every 50 dives;
> re-drill ±5 mm laterally and re-mount if wallowed.

---

## 9. Mount design proposal

### 9a. Primary variant — BR2 Roof Rack forward-mount

**Top face (chassis-side):** 2× M5 clearance holes matching the **Newton
pattern on the Roof Rack** — i.e. inherit Newton's bracket footprint so our
adapter drops into the existing Newton position with no chassis modification.

| Quantity | Value | Source |
|---|---|---|
| Top-face hole count | 2 | matches Newton bracket |
| Top-face hole pitch | 100 mm | matches Newton drilling template [3] |
| Top-face hole Ø | 5.5 mm clearance | matches Newton drilled holes [3] |
| Top-face hole offset to adapter centreline | 16 mm and 31 mm (or symmetric per measured rack) | matches template; **measure Roof Rack before drilling final** |
| Top-face tilt (built into adapter) | 16° | matches Newton template canted axis |
| Top-face material | PA12-GF printed *(production)*; PETG-HF *(prototype)* | repo material policy `../docs/MATERIALS.md` |
| Compliance pad | 3 mm Bambu TPU 95A HF, footprint = top face + 5 mm border | §8b |
| Top-face fasteners | 2× A4-316 M5×20 button-head + Loctite 243 | longer than Newton's M5×16 to account for 3 mm pad |

**Bottom face (gripper-side):** 4× M4 on the existing 40–50 mm bolt circle of
the gripper's bottom flange (`../ROV_INTEGRATION.md §1a`).

| Quantity | Value | Source |
|---|---|---|
| Bottom-face hole count | 4 | gripper M4 flange [`../ROV_INTEGRATION.md` §1a] |
| Bottom-face hole pitch | ~40–50 mm bolt circle (confirm from `gripper.py`) | shipped flange geometry |
| Bottom-face fasteners | 4× A4-316 M4×30 + nylon/PTFE bushings (galvanic isolation) | `../ROV_INTEGRATION.md` §1b |
| Drain holes | Yes — 2–4× Ø3 mm in adapter floor to prevent water trapping in the saddle | flooded-gripper policy |

**Shape:** A wedge — top face canted 16° to match the Roof Rack Newton slot,
bottom face flat to mate the M4 flange. Estimated envelope **80 × 70 × 35 mm,
~45 g in PA12-GF *(estimate)***.

**Cable channel:** A 6 mm-Ø open trench from the canister side of the adapter
out to the BR2-side, routing the gripper canister's M10-4.5mm-LC pigtail
along the Roof Rack toward the rear electronics-tube end cap. The cable does
**not** pass through the adapter body — it runs externally along the rack.

**Optional production variant:** Same geometry milled from **AL 6061-T6** for
salt/UV-tolerant high-cycle operations (T3-leaning service). Mass climbs to
~120 g *(estimate)*.

### 9b. Secondary variant — BR2 bottom-panel belly-mount (Newton pattern)

**Top face:** Same 2× M5 / 100 mm-pitch / 16° tilt — but now bolted to the
**factory-drilled BR2 bottom panel** holes the customer drilled when they
installed (or would have installed) a Newton.

**Pros over Roof Rack mount:**
- Lower aerodynamic profile — gripper hangs under the keel, doesn't add bow
  drag.
- Better COM (gripper directly below the existing ballast lead pattern).
- No interference with Lumen / Ping360 / sonar that compete for the Roof
  Rack.

**Cons:**
- Gripper not in main camera frustum unless the BR2's main camera is
  re-aimed downward.
- Adds bottom-strike risk — the gripper now hangs below the keel skids and
  is the first thing to touch the seabed.

**Adapter geometry differs only in the top-face tilt** — the bottom panel
Newton pattern is on a 16° canted line, so the adapter rotates the gripper
to point its jaws **downward at the same 16°** as Newton's natural
orientation. **Two variants of the same adapter — same top hole pattern,
same bottom flange pattern, just bolted to different chassis surfaces.**

### 9c. T-slot custom-ROV variant (bonus)

Replace the top-face 2× M5 / 100 mm-pitch pattern with **a 20 mm-pitch
multi-hole strip** so the adapter can mount to any 20 × 20 mm extrusion
T-slot at any spacing that's a multiple of 20 mm. Same bottom-face M4
flange pattern. This single change opens compatibility to any custom
T-slot ROV build — a large community population for which no vendor
gripper exists. (Out of scope for v1 ship — note as future.)

### 9d. What we are explicitly **not** designing

- **Wet-mate connectors.** The mount uses BR's compression-gland WetLink
  flow.
- **Active vibration damping.** Passive TPU pad only.
- **Bracket-mounted camera.** The BR2 already has a main camera; we point
  the gripper into its frustum, not the other way around.

---

## 10. Other ROV families — compatibility notes

### 10a. Chasing M2 / M2 Pro / M2 Pro Max

- Vendor manipulator (Grabber Arm 2) is **the only published path**: 7 kgf
  grip, 170 mm range, 2.8 s actuation, 100 m depth [9].
- Mount to the M2 Pro Max requires vendor **Mounting Bracket P/N 121129**;
  no public drawings of its bolt pattern [9].
- Verdict: **third-party gripper not viable** without reverse-engineering
  the 121129 bracket. Out of scope for our adapter family.

### 10b. QYSEA FIFISH V6 / V6S / V6 EXPERT / V-EVO

- Vendor "Robotic Arm Mount Kit" (1 arm mount + 2 holders) is the only
  documented chassis interface [10] [11].
- "Over 20 professional tools" all share **one undocumented accessory port
  / tool slot** [11].
- Verdict: same as Chasing — vendor-locked; we'd need to buy the mount kit
  and reverse-engineer it.

### 10c. OpenROV Trident

- Discontinued (OpenROV out of business since 2019); units still in the
  field.
- Body **410 × 205 × 86 mm, 3.5 kg** [15].
- Kickstarter update #10 announced a "payload interface" rear bay but
  dimensions were never publicly released [16].
- Community grippers exist (Thingiverse rubber-band claws [17]) but no
  documented chassis bolt pattern.
- Verdict: out of scope; community-only ecosystem with no canonical
  interface.

### 10d. Custom T-slot ROVs

- 20 × 20 mm aluminium extrusion (V-slot or T-slot) with M5 T-nut hardware.
- Any face, any pitch (20 mm multiple).
- This is the broadest target by population — but every build is bespoke.
- Our §9c variant (multi-hole 20 mm strip) is the right primitive.

### 10e. Reach Bravo manipulator (counter-reference)

- **Not a chassis interface** — it's the work-class manipulator counter-
  point. End-effector plate via Reach's "Payload Interface" [12].
- Listed here only to mark the boundary: chassis-mount is the cheap path,
  Bravo is the expensive path. The Bravo lives in `../ROV_INTEGRATION.md`
  and the *manipulator interface* studies (separate files).

---

## 11. Open questions / what we couldn't verify

| # | Item | Status | Path to close |
|---|---|---|---|
| Q1 | Newton bracket outer dimensions (length, width, plate thickness) | Not published by BR | Buy a Newton, measure; OR photogrammetry from BR product photos (low confidence) |
| Q2 | Roof Rack per-feature hole coordinates | Not published in usable form | Buy a Roof Rack and measure; BR's product-page drawing is referenced but un-recoverable in the publicly-served PDF/page content |
| Q3 | Claim "25 mm M3 grid on BR2 side plates" (task brief) | **Not confirmed** by any BR primary source we could fetch (datasheet, store, GitHub specs, R3 assembly guide, payload skid guide) | Likely conflation with another vehicle; treat as **unverified** until a BR drawing is found |
| Q4 | Newton 16° tilt — *why* 16° specifically | Inferred from template; BR does not document the design rationale | Email BR support (`support@bluerobotics.com`) |
| Q5 | Stack mass in §6a | All estimates (no live-CAD measure yet) | Update once BR-102649-240 canister + XW540 are weighed |
| Q6 | Stack net buoyancy in seawater | Computed from approximate volumes | Float the actual assembly in a saltwater tank |
| Q7 | Chasing P/N 121129 bracket bolt pattern | Vendor-only | Buy/borrow a M2 Pro Max bracket |
| Q8 | QYSEA accessory port dimensions | Vendor-only | Buy/borrow a Robotic Arm Mount Kit |
| Q9 | Trident payload interface dimensions | Never published; vendor defunct | None — accept as undocumented |
| Q10 | "Was there a Newton drilling template revision after R1?" | The PDF we fetched is dated 2018-05-31, marked "R1." | Re-check BR website periodically |

---

## 12. Sources

1. **BR2 Specifications (GitHub).** `bluerobotics/bluerobotics.github.io/blob/master/brov2/specifications.md` — vehicle dimensions, weight, buoyancy, ballast, depth ratings, tether. <https://github.com/bluerobotics/bluerobotics.github.io/blob/master/brov2/specifications.md>
2. **Newton Subsea Gripper product page (Blue Robotics).** SKU BR-100789, USD 720; jaw, grip, voltage, current, mass, depth, mount kit contents. <https://bluerobotics.com/store/thrusters/grippers/newton-gripper-asm-r2-rp/>
3. **Newton Subsea Gripper Installation on a BlueROV2 (Blue Robotics Learn).** Drilling-template reference, M5×16 fasteners, M10 penetrator, install sequence. <https://bluerobotics.com/learn/newton-subsea-gripper-installation/>
4. **BlueROV2 Frame product page (BR-100118).** Panel materials/thicknesses, M3/M4/M5 fastener schedule, 316 SS hardware list, AL6061-T6 cradles. <https://bluerobotics.com/store/rov/bluerov2-components-spares/brov2-asm-frame/>
5. **BlueROV2 Machined Buoyancy Foam.** R-3318 syntactic foam upgrade adds 500 g positive buoyancy; 300 m rated; standard on R3 and later. <https://bluerobotics.com/store/rov/bluerov2-accessories/float-r3318-brov2-r1-rp/>
6. **BlueROV2 Roof Rack product page.** AL 5052-H34, 177 g, USD 57; pre-drilled hole sets for WTE clamps, Lumen lights, Ping360, **Newton (×2)**, Sonoptix Echo, 1/4-20 tripod. <https://bluerobotics.com/store/rov/bluerov2-accessories/rov-roof-rack/>
7. **Installing the BlueROV2 Roof Rack (Learn article).** 4× M5×12 top-mount; 4× M3×12 front-mount via Lumen holes; 0° and 10° tilt options; blue threadlocker. <https://bluerobotics.com/learn/installing-the-bluerov2-roof-rack/>
8. **Autonomous Lionfish Harvester (Blue Robotics blog).** BR-promoted reference application; uses Newton on a BR2. <https://bluerobotics.com/autonomous-lionfish-harvester/>
9. **CHASING Grabber Arm 2 (vendor and resellers).** Vendor bracket P/N 121129; 7 kgf, 170 mm range, 2.8 s, 100 m depth. <https://www.focusnordic.com/products/drones/underwater-drones/propellers-parts-power/chasing-m2-pro-max-grabber-robotic-arm-quick-mounting-bracket>
10. **QYSEA Robotic Arm Mount Kit for FIFISH V6 Series.** 1 arm mount + 2 holders. <https://www.blueskiesdroneshop.com/products/qysea-fifish-v6-series-robotic-arm-mount-kit>
11. **QYSEA FIFISH V-EVO product page.** Standard + Robotic Arm Pack option; "attachment port accommodates a variety of tools." <https://store.qysea.com/fifish-v-evo.html>
12. **Reach Bravo Payload Interface (Reach Robotics).** Plate-style end-effector mount for Bravo manipulator; chassis-mount counter-point. <https://quote.reachrobotics.com/product/bravo-accessories-upgrades/payload-interface/>
13. **The role of conservation volunteers in the detection, monitoring and management of invasive alien lionfish (Blue Ventures publication).** Citizen-science use of inspection-class ROV tooling. <https://blueventures.org/publications/role-conservation-volunteers-detection-monitoring-management-invasive-alien-lionfish/>
14. **BlueROV2 Payload Skid product page (BR-100233).** 475 × 338 × 197 mm, 1200 g, HDPE + AL6061-T6; 12 ballast slots, 8× M5×16 attachment; USD 320. <https://bluerobotics.com/store/rov/bluerov2-accessories/brov-payload-skid/>
15. **OpenROV Trident specifications.** 410 × 205 × 86 mm, 3.5 kg. <https://openrov.com/products/trident/specifications>
16. **Trident Kickstarter Update #10 — Payload Interface: Mechanical.** Forum post announcing the payload bay; dimensions never publicly released. <https://forum.openrov.com/t/payload-interface-mechanical-trident-kickstarter-update-10/4615>
17. **ROV Claw Gripper for OpenRov Trident (Thingiverse).** Community 3D-printed rubber-band claw; representative of post-OpenROV ecosystem. <https://www.thingiverse.com/thing:2753801>
18. **BlueROV2 R3 Assembly and Build Instructions (Learn).** Side panel / centre panel / bottom panel composition; M5×16 frame fasteners; M4×18 / M4×14 cradle and clamp fasteners. <https://bluerobotics.com/learn/bluerov2-assembly-r3-version/>
19. **BlueROV2 Payload Skid Assembly Guide (Learn).** Fastener schedule; 8× M5×16 to ROV; M3×12, M4×14, M5×16, M5×20 stations. <https://bluerobotics.com/learn/bluerov2-payload-skid-assembly-guide/>
20. **Blue Robotics WetLink Penetrator family.** Compression-gland through-hull penetrator series; M10 body size for typical thruster/gripper cables; ≤950 m rated. <https://bluerobotics.com/store/cables-connectors/penetrators/wlp-vp/>

### Local cross-references (this repo)

- `../ROV_INTEGRATION.md` — manipulator-arm-side mount (M4 flange detail); the **arm** sibling of this **chassis** file.
- `../SELECTION.md` — actuator class / depth-tier decision.
- `../REQUIREMENTS.md` — input-shaft torque / mass / depth requirements.
- `../DRIVETRAIN.md` — gear ceiling; sets the *upstream* structural limit the mount must not exceed.
- `../ELECTRICAL.md` — RS-485 + 12 V termination inside the BR2 electronics enclosure.
- `../FAILURE_MODES.md` — failure mode catalogue; this file adds **HDPE bore wallowing** (§8c) and **bow-impact cantilever** (§8c).
- `../docs/UNDERWATER.md` §5 — galvanic isolation policy (re-used at §9a fastener stack).
- `../docs/MATERIALS.md` — printed-material selection; PA12-GF for production adapter, Bambu TPU 95A HF for the compliance pad.

---

*File created 2026-05-26 as the chassis-mount counterpart to `motor/ROV_INTEGRATION.md`. Every BR-published number is referenced to a numbered source. Numbers marked **(estimate)** are derived, not measured — close before bench validation per `../BENCH_TEST.md`.*

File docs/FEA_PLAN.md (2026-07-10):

# FEA plan — gripper stats + FEA-driven finger morph for the underwater render

**Run location decision (final):** FEA ran **locally on the Linux workstation**
(`.cad-venv` with build123d — needed to extract the Fin Ray cross-section; the
solve is a small 2D CPU job, no GPU benefit). The **photoreal render only** ran
on a **Windows RTX-3070 workstation** (Blender 5.1) — that is the genuinely
heavy, GPU-bound task.

---

## Why 2D plane-strain is the CORRECT model (not a simplification)
UNDERWATER §3: the Fin Ray finger is a **2.5-D extrusion through the full 10 mm Z
depth** — every rib/cell is constant in Z. The Fin Ray effect is inherently a 2D
truss mechanism; full 3D adds mesh pain, not physics. So the finger compliance is a
**plane-strain 2D problem**, extruded back to 10 mm for the render.

## Solver
`scikit-fem` (pip into the venv; pure Python; 2D plane-strain; incremental Newton
for geometric nonlinearity; penalty-method contact against the rigid artifact).
`meshio` + `matplotlib` for IO + the stress/deformation animation.

## Deliverable 1 — Fin Ray finger compliance (the centerpiece)
- Extract the finger cross-section polygon from `gripper.py` (build123d section at
  mid-Z), mesh it (triangles).
- Material: TPU ~95A, neo-Hookean (or Mooney-Rivlin). **Coefficients are ASSUMED
  literature values for 95A, not measured on the print** — stated in FEA_NOTES.
- Boundary conditions: fix the mount eyes (C/D pivot region); drive the actuation by
  prescribing the finger base motion through the `GRIPPER_OPEN` closing stroke;
  rigid circular artifact boundary as a penalty contact obstacle.
- Outputs: per-step deformed node field (`finray_morph_<frame>.npz`) = the Blender
  morph driver; von Mises field; **grip/contact reaction force vs actuation** curve.

## Deliverable 2 — rigid load-path stats (linear-elastic)
Quick linear-elastic 2D/section checks → max von Mises + deflection + FoS vs
material allowable, to corroborate the repo hand-calcs:
- snap clip cantilever (repo: 1.36 % worst-tight strain, PA12-GF)
- ~~finger-pin barb seat / counterbore shoulder (2.78 % insertion)~~ **obsolete** — pins no longer flex; retention is now a melted PETG-HF cap head (geometric formed head, no insertion strain to check)
- gear tooth root (drive torque) and drive-arm at the C-eye boss
Emit `stats.json` + `stats.md`.

## Deliverable 3 — sediment is a Blender SIM SPEC, not FEA
Do not FEM the sediment. The FEA supplies the **grip-break force** that justifies
*when* the artifact releases from the silt; the sediment dynamics (particle emit on
break, Stokes-drag drift, slow settle) are authored in Blender. Spec goes in the
render prompt.

## Pre-declared convergence escape valves (planned graceful degradation)
1. If hyperelastic + penalty contact won't converge → drop to **geometrically-
   nonlinear linear-elastic (corotational / Saint-Venant–Kirchhoff)**. Still a
   physical deformation field, far more robust.
2. If the full closing stroke diverges → solve **piecewise**: short load
   increments, store each converged step, animate the sequence. Never one big solve.

## Honesty floor (ships in fea/FEA_NOTES.md)
- TPU coefficients assumed (cite typical 95A), not measured.
- Plane-strain assumption (justified by Z-extrusion geometry).
- Contact = penalty method, friction value stated.
- Rigid four-bar motion is EXACT (kinematics); finger compliance is FEA; sediment is
  artistic Blender sim. The render is **"FEA-driven compliance + keyframed kinematics
  + artistic sediment"** — NOT "fully simulated physics."

## Bundle (copied to the render workstation)
```
/home/andre/Projects/softsense/render_bundle/
  geometry/   per-part GLB + per-part transform JSON (the rigid kinematics morph)
  fea/        stats.json, stats.md, finray_morph_<frame>.npz, stress_animation.mp4,
              force_curve.png, FEA_NOTES.md
  prompt.txt  PC-ready Blender prompt referencing these bundle paths
  README.md   contents + what is exact vs approximated
```

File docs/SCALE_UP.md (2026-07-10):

# Scale-up: 1.5× and 2.0× variants (underwater-archaeology sizing)

The shipped 1× gripper is small (jaw opens to ~118 mm at the fingertips, per-finger
force 0.14–0.73 N) — too small and too weak to recover typical underwater-archaeology
finds. This rebuild scales the **entire** gripper **self-similarly** to two larger
sizes, **1.5×** and **2.0×**, and re-runs every sim/FEA/stat at the new sizes.

Both variants are generated from the same parametric source by one env var:

```bash
GRIPPER_SCALE=1.5  python scripts/export_parts.py     # -> variants/scale_1.5x/parts
GRIPPER_SCALE=2.0  python scripts/export_parts.py     # -> variants/scale_2.0x/parts
```

`SCALE=1.0` reproduces the canonical 1× model byte-for-byte (the scaling code is
proven neutral at 1×), so the original design is preserved as the reference.

---

## 1. What "self-similar" means here (and what does NOT scale)

Every **linear design dimension** is multiplied by the scale factor `k` — the linkage
(crank/follower/coupler), the gears (pitch radii, tooth heights, face widths), the
**finger walls** (the key fix — see §3), the enclosure, the input shaft, the flange,
and the snap-clips. Because lengths, radii and thicknesses all scale together, the
**wall/blade ratio, gear module ratio, and every angle are preserved** — true
mechanical similitude. (Verified: finger rotation is identical −20.07° at 1.0/1.5/2.0×,
and the kinematic opening scales exactly ×k.)

Deliberately **held constant** (these are not functions of part size), each documented
inline in `gripper.py`:

| Held | Why |
|---|---|
| Print/tolerance clearances (`PRINT_CLEAR` 0.3, mesh/bore running gaps, heat-stake pin/cap & bore running clears) | Set by the 0.4 mm FDM nozzle, not the part. The *nominal* scales, the additive gap is held → running fits stay ~0.3 mm at every scale. |
| Fastener sizes (M4 bolts, M3 taps) | An M4 is M4 at any scale; only the bolt-pattern **positions** scale. (See §6 — at 2× consider M5/M6 for the higher loads.) |
| Flood / drain / vent hole **radii** | Sized by absolute bubble/surface-tension + FDM-floor physics; positions scale. |
| Edge-break chamfers / fillets (`DFM_EDGE`, `CHAM_*`, `R_VERT`, finger fillets) | Manufacturing finishes; held (also keeps fillet ops robust). |

The grip **micro-texture** (crosshatch posts) **does** scale (channels 0.54→0.81→1.08 mm)
— this is grip-safe because the wet-grip campaign found grip is *grip-neutral above a
~0.3 mm channel* (drainage saturates), and every scaled channel stays above that. Scaling
it (vs holding absolute) keeps the post **count** constant, which is what makes the bigger
finger printable in reasonable time.

---

## 2. Size & kinematics (verified from the CAD)

| Quantity | 1.0× (ref) | **1.5×** | **2.0×** |
|---|---|---|---|
| Finger blade length | 90 mm | **135 mm** | **180 mm** |
| Jaw opening at tip (open) | 124 mm | **186 mm** | **248 mm** |
| Jaw opening at base (open) | 62 mm | 93 mm | 124 mm |
| Jaw gap (closed) | 9.9 mm | 14.8 mm | 19.7 mm |
| Assembly footprint (bbox) | 100.8 × 31 × 162 | 150.8 × 46.5 × 243 | 200.8 × 62 × 324 mm |
| Solid material volume | 56.5 cm³ | 197.4 cm³ | 473.4 cm³ |
| ≈ printed mass (100 % dense, ~1.15 g/cm³) | ~65 g | **~0.23 kg** | **~0.54 kg** |
| Longest single part | 100.8 mm | 151 mm | 201 mm |
| Print plates (256 mm P1S bed) | 3 | **3** | **4** (rigid splits to 2) |

All parts fit the 256 mm Bambu P1S bed at both scales (`make_print_plates` raises if a
part exceeds the bed — clean pass at 1.5× and 2.0×).

---
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

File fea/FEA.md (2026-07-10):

# FEA — Fin Ray finger compliance & snap-clip verification

Finite-element validation that the gripper's compliant grasp is **gentle enough for
fragile finds** (the underwater-archaeology use case) and that the load-bearing
snap features are within their material limits. Two related (not independent) FEA
formulations were run and **agree in order of magnitude** on the fragility metric:
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

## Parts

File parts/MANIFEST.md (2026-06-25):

# Gripper print manifest

Generated by `export_parts.py` from `gripper.gen_step()` at the **CLOSED** pose (`GRIPPER_OPEN=0`).

**This gripper is FULLY 3D-PRINTED -- zero bought hardware.** The pivot pins are printed PETG-HF HEAT-STAKE pins (a separate cap is melted onto each pin's stud with a soldering iron) and the front cover snaps on with integral cantilever clips. Every part below is printed.

STL mesh tolerance: `0.05 mm` (linear), `0.1` (angular). Each part is translated so its bounding-box min corner is at the origin.

| Part | Qty | Printable | Material | Bbox (mm) | Instances | Print orientation |
|---|-----|---|---|---|---|---|
| `enclosure.step`/`.stl` | 1 | yes | PETG / Nylon | 96.0 x 41.0 x 28.0 | enclosure | open cavity face UP on the bed (back flange down); supports only inside the shaft bore. |
| `drive_arm_R.step`/`.stl` | 1 | yes | PA12-GF | 26.4 x 50.4 x 11.9 | drive_arm_R | lay the flat gear+arm plate face-down on the bed (5 mm thick). Both arms ride on the heat-stake axle pins (no integral shaft). |
| `drive_arm_L.step`/`.stl` | 1 | yes | PA12-GF | 26.1 x 50.2 x 11.9 | drive_arm_L | lay the flat gear+arm plate face-down on the bed (5 mm thick). Both arms ride on the heat-stake axle pins (no integral shaft). |
| `follower.step`/`.stl` | 2 | yes | PETG / Nylon | 10.4 x 39.3 x 6.4 | follower_R, follower_L | lay the flat link bar face-down on the bed (5 mm thick). |
| `finger_R.step`/`.stl` | 1 | yes | TPU (shore ~95A) | 29.2 x 96.1 x 10.0 | finger_R | lay the Fin Ray plane FLAT on the bed, RIDGE (contact-face) side DOWN for clean grip ridges; the 10 mm depth is the Z height (may want a 90 deg rotate from the exported pose). |
| `finger_L.step`/`.stl` | 1 | yes | TPU (shore ~95A) | 29.2 x 96.1 x 10.0 | finger_L | lay the Fin Ray plane FLAT on the bed, RIDGE (contact-face) side DOWN for clean grip ridges; the 10 mm depth is the Z height (may want a 90 deg rotate from the exported pose). |
| `melt_pin_axle_AR.step`/`.stl` | 1 | yes | PETG-HF | 7.8 x 7.8 x 28.7 | pin_A_R | stand the pin AXIS VERTICAL, HEAD DOWN, melt-stud UP; no supports (plain stepped cylinder, collar prints as a self-supporting band). Finger pins: _finger_C long (crank layer), _finger_D short (follower layer). Axle pins differ by collar height: _axle_AR (crank), _axle_AL (crank+crown), _axle_B (follower). After assembly, slip a melt_cap on the protruding stud and fuse it. |
| `cotter.step`/`.stl` | 4 | yes | PETG / Nylon | 4.4 x 1.0 x 1.0 | cap_A_R, cap_B_R, cap_A_L, cap_B_L | orientation TBD -- inspect and lay the largest flat face on the bed. |
| `melt_pin_axle_B.step`/`.stl` | 2 | yes | PETG-HF | 7.8 x 7.8 x 28.7 | pin_B_R, pin_B_L | stand the pin AXIS VERTICAL, HEAD DOWN, melt-stud UP; no supports (plain stepped cylinder, collar prints as a self-supporting band). Finger pins: _finger_C long (crank layer), _finger_D short (follower layer). Axle pins differ by collar height: _axle_AR (crank), _axle_AL (crank+crown), _axle_B (follower). After assembly, slip a melt_cap on the protruding stud and fuse it. |
| `melt_pin_finger_C.step`/`.stl` | 2 | yes | PETG-HF | 7.8 x 7.8 x 24.8 | pin_C_R, pin_C_L | stand the pin AXIS VERTICAL, HEAD DOWN, melt-stud UP; no supports (plain stepped cylinder, collar prints as a self-supporting band). Finger pins: _finger_C long (crank layer), _finger_D short (follower layer). Axle pins differ by collar height: _axle_AR (crank), _axle_AL (crank+crown), _axle_B (follower). After assembly, slip a melt_cap on the protruding stud and fuse it. |
| `melt_cap.step`/`.stl` | 4 | yes | PETG-HF | 5.2 x 5.2 x 2.6 | cap_C_R, cap_D_R, cap_C_L, cap_D_L | tiny cup: print OPEN-END UP (closed crown on the bed) so the blind pocket needs no bridging; no supports. Slip over a pin's melt-stud and fuse the crown with a soldering iron. |
| `melt_pin_finger_D.step`/`.stl` | 2 | yes | PETG-HF | 7.8 x 7.8 x 19.3 | pin_D_R, pin_D_L | stand the pin AXIS VERTICAL, HEAD DOWN, melt-stud UP; no supports (plain stepped cylinder, collar prints as a self-supporting band). Finger pins: _finger_C long (crank layer), _finger_D short (follower layer). Axle pins differ by collar height: _axle_AR (crank), _axle_AL (crank+crown), _axle_B (follower). After assembly, slip a melt_cap on the protruding stud and fuse it. |
| `melt_pin_axle_AL.step`/`.stl` | 1 | yes | PETG-HF | 7.8 x 7.8 x 28.7 | pin_A_L | stand the pin AXIS VERTICAL, HEAD DOWN, melt-stud UP; no supports (plain stepped cylinder, collar prints as a self-supporting band). Finger pins: _finger_C long (crank layer), _finger_D short (follower layer). Axle pins differ by collar height: _axle_AR (crank), _axle_AL (crank+crown), _axle_B (follower). After assembly, slip a melt_cap on the protruding stud and fuse it. |
| `front_cover.step`/`.stl` | 1 | yes | PETG / Nylon | 100.8 x 36.0 x 23.5 | front_cover | outer face DOWN on the bed, snap clips pointing UP; the clips print as unsupported cantilevers off the inner face -- no supports needed. |
| `input_pinion_shaft.step`/`.stl` | 1 | yes | PA12-GF | 11.6 x 35.0 x 11.6 | input_pinion_shaft | print shaft-axis VERTICAL: rotate 90 about X so the shaft stands up; D-coupler/shoulder end DOWN on the bed (r=5.0mm, wider base), pinion teeth UP. Shaft cylinder = self-supporting rings; the bottom shoulder bridges ~1.8mm radially (1-2 layers). SUPPORTLESS. Installs into the housing FROM BELOW (pinion-first). |

## Notes

- **Everything is printed.** No screws, no dowel pins, no bought fasteners. The axle pins (x4 = `melt_pin_axle_AR` + `melt_pin_axle_AL` + `melt_pin_axle_B` x2), `melt_pin_finger_C` (x2, long crank-layer pin), `melt_pin_finger_D` (x2, short follower-layer pin) and `melt_cap` (x4) are PETG-HF HEAT-STAKE pivots (shank radius PIN_R = 2.3 mm). Each pin has a locating collar so its element cannot slide axially; retention is a geometric melted head (no broken barbs, no pins sliding out).
- **Heat-stake pins: print HEAD DOWN, axis vertical, no supports.** Insert the pin, slip a `melt_cap` over the protruding stud (open end toward the part), and fuse the cap crown with a soldering iron -> a rivet head wider than the bore. Finger pins (C/D) are staked at the arm/follower-eye bottom on the bench; axle pins (A/B) are staked on the EXTERIOR back face. See docs/ASSEMBLY.md.
- **Front cover snaps on (no screws).** It carries 4 integral cantilever clips (2 per long side) that hook into the body side-wall windows. Print outer-face DOWN, clips UP. Push on to click; flex the 4 hooks outward to release.
- **Fingers are chiral.** `finger_R` and `finger_L` share a bounding box / volume but are mirror images (Fin Ray ribs all slant the same way within a finger), so both are exported. Print in TPU, ridge side down.
- **Followers are identical.** A follower is a symmetric link bar; left and right are the same part -> one file, qty 2.
- **Drive arms differ.** `drive_arm_L` carries the crown gear on its +Z face (right-angle stage); `drive_arm_R` is a plain gear+arm plate. Both arms ride on the heat-stake axle pins -- neither has an integral shaft. The input shaft is a separate part: `input_pinion_shaft`.
- **input_pinion_shaft** (pinion + vertical shaft + bottom shoulder + D-coupler) prints shaft-axis VERTICAL (rotate 90° about X from exported pose): D-coupler/shoulder end on bed (r=5.0 mm, wider base), pinion teeth up. Supportless. Installs into the housing from below, pinion-first.

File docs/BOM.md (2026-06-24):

# Bill of Materials — Underwater geared four-bar / Fin Ray gripper (FULLY 3D-PRINTED)

Production BOM for the gripper defined in `gripper.py` (geared four-bar, single
input shaft, compliant TPU Fin Ray fingers, **flooded** housing for underwater
use). This is the *what-to-print* list — and for this revision that is the
**entire** list. See `PRINTING.md` for how to orient and slice each part,
`UNDERWATER.md` for material chemistry in seawater, and `ASSEMBLY.md` for the
tool-free snap-together sequence.

> # ZERO bought hardware inside the gripper. No screws, no nuts, no bolts, no bushings.
> **Every gripper part is 3D-printed and snaps, slides, or heat-stakes together by hand —
> tool-free except for a soldering iron at the pin caps.** All 8 pivot pins are plain
> printed journal pins, each retained by a separate printed cap melted over the pin's
> protruding stud with a soldering iron (a thermal rivet head wider than the bore). The
> 4 axle pins rivet to the back wall through the existing flood holes; the 4 finger pins
> (two SKUs, C and D, at different Z depths) cap on the arm/follower-eye underside as a
> bench sub-assembly. The front cover
> is held by 4 integral printed cantilever snap clips. The input shaft turns in
> two flooded journal bearings — no metal bushing. The **only** non-printed items
> in the whole system are the user's waterproof actuator (bottom D-shaft) and,
> at the robot-arm interface, the user's M4 mount bolts + nylon/PTFE
> galvanic-isolating washers (per `UNDERWATER.md` §5).

Headline build target: **flooded, all-polymer, fastener-free.** Nothing to seal,
nothing to buy inside the gripper, and no metal anywhere in the gripper.

---

## 1. Printed parts (the complete BOM)

Everything below is emitted by `gripper.gen_step()` (verified against the live
`gen_step()` output: 25 children, labels as listed). The enclosure floods through
its drain holes; the mechanism drops in; each axle pin drops through its bore and
rivets to the back wall through the existing flood hole; each finger pin is melt-capped
on the arm/follower-eye underside as a bench sub-assembly; the cover snaps on. Done.

**Material legend:** FINAL = production print material. TEST = test-print material.
The 8 pivot pins and their 8 melt caps are PETG-HF (so they melt cleanly under a
soldering iron) — the sole exception to the otherwise all-PA12-GF rigid build; see
note below the table.

| Part | Qty | **FINAL material** | Test-print | Rough filament | Role / key detail |
|---|---|---|---|---|---|
| `enclosure` | 1 | **PA12-GF (Nylon 12 glass-filled)** | PETG-HF | ~80–110 g | Flooded gearbox body. Open front, flush, full-width integrated base with chamfered bottom perimeter (4 × M4 clearance holes), top link slots, 4 back-wall axle bosses + stepped bores (wide running bore + narrow flood hole), upper + lower journal bores + collar pocket for the vertical input shaft in the bottom wall, bottom drains (4 positions × 2 Z = 8 holes) + 2 side drains, 4 snap-clip catch windows in the long side walls. Never PLA. |
| `front_cover` | 1 | **PA12-GF** | PETG-HF | ~20–30 g | Closes the open front; 4 inner-face bosses locate the axle-pin heads (the heads seat just under these bosses — but the pins are riveted to the back wall by their melt caps, so the cover is no longer their retainer); **4 integral cantilever snap clips** (2 per long side, `SNAP_Z0=1.5` — lengthened arm, now slimmed to 2.0 mm thick so each tab stands just 2.4 mm proud of the side wall with a chamfered free-tip blade; 1.36 % worst-tight strain, within PA12-GF allowable) latch into body side-wall windows; **3 × Ø1.8 mm vent holes** at (±34, +12). Push on to click (click is a touch softer with the thinner arm); flex 4 hooks outward to release. |
| `drive_arm_R` | 1 | **PA12-GF** | PETG-HF | ~12–18 g | Right gear sector + crank arm. Clearance-bored at A_R (rides on axle pin `pin_A_R`). C-eye (−Z exit face) journals the slim land of finger pin `pin_C_R`; the pin's melt-stud exits below and is melt-capped. Flat plate; prints face-down. |
| `drive_arm_L` | 1 | **PA12-GF** | PETG-HF | ~12–18 g | Left gear sector + crank arm + **integral CROWN gear** on its +Z face (driven by the input pinion via the right-angle stage). Clearance-bored at A_L (rides on axle pin `pin_A_L`). C-eye journals `pin_C_L`. Flat plate; prints face-down. |
| `input_pinion_shaft` | 1 | **PA12-GF** | PETG-HF | ~8–12 g | ONE printed part: spur input pinion + vertical shaft + integral capture collar + bottom D-profile coupler (r 5.0, D-flat depth 1.4, length 12 mm). Axis vertical (exits the housing bottom). Two journal bearings in the housing (upper 2 mm, lower 7 mm); collar (OD 5.8 mm) trapped in a housing pocket between the two bore-mouth shoulders for axial capture (zero hardware). Print shaft-axis vertical for a self-supporting cylinder. |
| `follower_R` | 1 | **PA12-GF** | PETG-HF | ~6–9 g | Right B→D link bar. D-eye (−Z exit face) journals the slim land of finger pin `pin_D_R`; the pin's melt-stud exits below and is melt-capped. Flat plate; prints face-down. |
| `follower_L` | 1 | **PA12-GF** | PETG-HF | ~6–9 g | Left B→D link bar. D-eye journals `pin_D_L`. Same geometry as `follower_R` (mirrored in gen_step). |
| `finger_R` | 1 | **Bambu TPU 95A HF** (TPU ~95A — print ether-stable only) | TPU | ~30 g (ρ 1.22) | Right Fin Ray compliant jaw. Grip ridges on contact face; internal slanted-rib truss; mount holes at C_R and D_R. Must flex — print in TPU only. Print profile: `PRINT_PROFILE_P1S_TPU.md`. |
| `finger_L` | 1 | **Bambu TPU 95A HF** (TPU ~95A) | TPU | ~30 g (ρ 1.22) | Left Fin Ray compliant jaw (chiral mirror of `finger_R`). |
| `pin_A_R` (`melt_pin_axle`) | 1 | **PETG-HF** ★ | PETG-HF | ~1–2 g | **Axle pin** (heat-stake) for right drive-arm pivot (A_R). Head seats just under the cover boss; shank journals the gear/arm and bottoms on the back-bore step; melt-stud threads the existing back-wall flood hole and protrudes past the exterior back face, where its cap is melted from outside — riveted to the back wall (a fixed pivot post). No barb, no cover sandwich. |
| `pin_A_L` (`melt_pin_axle`) | 1 | **PETG-HF** ★ | PETG-HF | ~1–2 g | **Axle pin** (heat-stake) for left drive-arm pivot (A_L). Same geometry as `pin_A_R`. Added because `drive_arm_L` no longer carries an integral horizontal shaft — it now rides on this axle pin like the other arms. |
| `pin_B_R` (`melt_pin_axle`) | 1 | **PETG-HF** ★ | PETG-HF | ~1–2 g | **Axle pin** (heat-stake) for right follower pivot. Same geometry as `pin_A_R`. |
| `pin_B_L` (`melt_pin_axle`) | 1 | **PETG-HF** ★ | PETG-HF | ~1–2 g | **Axle pin** (heat-stake) for left follower pivot. Same geometry as `pin_A_R`. |
| `pin_C_R` (`melt_pin_finger_C`) | 1 | **PETG-HF** ★ | PETG-HF | ~1–2 g | **Finger pin** (heat-stake), LONG crank-layer SKU, for right crank-coupler joint (C_R). Head seats on the finger top; fat neck is the anti-wobble running bearing in the 2.6 mm TPU finger bore; slim land journals the rigid PA12-GF crank-arm C-eye; melt-stud protrudes past the C-eye bottom, where a separate cap is melted (bench sub-assembly). |
| `pin_D_R` (`melt_pin_finger_D`) | 1 | **PETG-HF** ★ | PETG-HF | ~1–2 g | **Finger pin** (heat-stake), SHORT follower-layer SKU, for right follower-coupler joint (D_R). Same head/neck/land/melt-stud arrangement; melt-stud capped past the follower D-eye bottom. |
| `pin_C_L` (`melt_pin_finger_C`) | 1 | **PETG-HF** ★ | PETG-HF | ~1–2 g | **Finger pin** (heat-stake), LONG crank-layer SKU, for left crank-coupler joint (C_L). |
| `pin_D_L` (`melt_pin_finger_D`) | 1 | **PETG-HF** ★ | PETG-HF | ~1–2 g | **Finger pin** (heat-stake), SHORT follower-layer SKU, for left follower-coupler joint (D_L). |
| `melt_cap` | 8 | **PETG-HF** ★ | PETG-HF | <1 g ea | **Heat-stake cap** — one per pin (qty 8). Slip over the pin's protruding melt-stud and fuse with a soldering iron → a thermal-rivet head wider than the bore. Retention is geometric (formed head larger than the hole), not an elastic snap and not a press fit. Negligible mass each. |

★ **All 8 pivot pins + their 8 melt caps — PETG-HF in the final build, not PA12-GF.**
The pins and caps are heat-staked: a separate cap is melted over each pin's protruding
stud with a soldering iron to form a thermal rivet head. PETG-HF is used for all of them
because they must **melt cleanly under a soldering iron** — glass-filled PA12-GF does not
heat-stake well (the glass loading resists clean reflow). Nothing flexes (retention is the
formed head, geometric, not an elastic snap) and nothing relies on friction (not a press
fit, so nothing slides out). Pull-out load is carried by the formed melt-cap head against
the eye/wall face, not by an interference fit. (See `MATERIALS.md` §3 / Fix 2A.)

\* Rough single-piece estimates at recommended walls/infill (`PRINTING.md`).
**Total filament: roughly ~120–175 g PA12-GF + ~50–70 g ether-TPU + ~5–10 g PETG-HF
(8 pins + 8 caps).** The 8 pins, 8 caps, and `input_pinion_shaft` together add roughly
12–18 g; each melt cap is tiny (<1 g).

---

### 1.1 Pin families: what makes each type work

Every pivot is a **heat-stake (melt-rivet) pin**: a plain printed PETG-HF journal
pin retained by a separate printed PETG-HF cap (`melt_cap`) melted over the pin's
protruding stud with a soldering iron, forming a thermal rivet head wider than the
bore. Retention is **geometric** (a formed head larger than the hole) — *not* an
elastic snap (nothing flexes → nothing breaks) and *not* a press fit (nothing relies
on friction → nothing slides out). There are **two pin layouts**, distinguished by
where the cap is melted; they are not interchangeable.

**Axle pins — `pin_A_R`, `pin_A_L`, `pin_B_R`, `pin_B_L` (4 pins, `melt_pin_axle`)**

The head seats just under the cover boss. The shank (r 2.3 mm) journals the
gear/arm and **bottoms on the back-bore step** (the wide running bore narrows to
the flood hole). The melt-stud threads the **existing back-wall flood hole** and
protrudes past the **exterior back face**, where its cap is melted **from outside** —
riveting the pin to the back wall as a **fixed pivot post**. The cover is no longer
the retainer and no longer sandwiches these pins; they stand on their own once
capped. Cap the axle pins (from outside the back wall) as part of dropping the
mechanism in; the cover snaps on afterward over a finished, retained axle set.

**Finger pins — `pin_C_R`/`pin_C_L` (`melt_pin_finger_C`, LONG/crank layer),
`pin_D_R`/`pin_D_L` (`melt_pin_finger_D`, SHORT/follower layer) — 4 pins, 2 SKUs**

C and D sit at **different Z depths** (crank layer vs follower layer), so they are
**two SKUs**, not one — the old single finger pin was wrong (half didn't seat). On
each: the head seats on the **finger top**; a **fat neck** is the anti-wobble running
bearing in the fixed 2.6 mm TPU finger bore; a **slim land** journals the rigid
PA12-GF arm/follower eye; the **melt-stud** protrudes past the arm/follower-eye
**bottom**, where a separate cap is melted. The finger pins are melt-capped as a
**bench sub-assembly** (finger + pin + cap built up off the gripper, then dropped in).

---

### 1.2 Material rationale (final build picks)

- **Structural / rigid parts → PA12-GF (Nylon 12 glass-filled), FINAL.**
  PA12 is the lowest-uptake engineering nylon (~0.7–1.2 % saturated; glass fill
  reduces it further). It does not hydrolyze and holds tight dimensions under
  sustained immersion. Glass fill gives ~3.5–5.5 GPa modulus and low creep —
  ideal for gearbox bodies, arms, and link bars. **PETG-HF** is
  used for test prints: same geometry fidelity, faster to iterate. **Never PLA**
  (hydrolyzes); no ester-based materials; no raw PA6/PA66 (high swell).

- **All 8 pivot pins + 8 melt caps (`melt_pin_axle` ×4, `melt_pin_finger_C` ×2,
  `melt_pin_finger_D` ×2, `melt_cap` ×8) → PETG-HF.** These are heat-staked: a
  separate cap is melted over each pin's stud with a soldering iron to form the
  retaining rivet head. They must **melt cleanly under a soldering iron**, and
  glass-filled PA12-GF does **not** heat-stake well (the glass loading resists
  clean reflow). So all pins moved PA12-GF → PETG-HF along with the caps. Nothing
  flexes — retention is the formed head, geometric, not elastic — so the old
  barb-ductility/insertion-strain argument no longer applies. Pull-out load is the
  melt-cap head bearing against the eye/wall face. **Never TPU for any pin**
  (creeps under sustained load, wallows bores) and TPU will not form a clean
  rivet head.

- **Fingers → TPU ~95A; selected filament Bambu TPU 95A HF.** The Fin Ray
  grip principle is material compliance — the fingers must flex to wrap an object.
  **Ether-based** TPU is hydrolysis-stable in sustained/warm immersion. **Ester-based
  TPU hydrolyzes** and crumbles underwater — exclude it entirely. *Bambu's TDS lists
  the material as thermoplastic polyurethane, "insoluble in water", with low saturated
  water uptake (1.08 % at 25 °C/55 %RH) — but it does NOT state polyether vs polyester
  chemistry, so we cannot claim hydrolysis resistance from the datasheet. For sustained
  or mission-critical immersion, confirm a polyether grade with Bambu or soak-test
  first.* TDS (Bambu TDS V1.0, ISO 527 printed specimens): density 1.22 g/cm³ (ISO 1183),
  tensile strength 27.3 MPa in-plane (X-Y) / 22.3 MPa through-Z (ISO 527 printed,
  Bambu TDS), elongation >650 % (X-Y) / >480 % (Z). Melting temp 183 °C. "HF" =
  high-flow: ~3× the throughput of standard TPU 95A (max volumetric speed ~12 mm³/s,
  prints up to ~200 mm/s; external-spool only — Bambu rates 95A HF too soft for the AMS). Print profile + FEA validation:
  `PRINT_PROFILE_P1S_TPU.md`. 95A shore balances conformance with grip force; softer
  (85A) for delicate objects, stiffer (98A) for more grip force.

---

## 2. Zero bought hardware inside the gripper — what this revision eliminated

**This is a fully 3D-printed, zero-hardware gripper interior.** No screws, no
nuts, no bolts, no washers, no bushings inside the gripper body. Assembly is
tool-free apart from a soldering iron at the caps: drop in the printed axle pins
and rivet them to the back wall (melt a cap on each stud from outside), install
the input-pinion-shaft, build up the finger+pin+cap bench sub-assemblies, drop
them in, snap on the cover. Disassembly: flex the cover clips, snip or shave the
melt caps, and lift out the pins (the caps are sacrificial — reprint and re-stake).

| Obsolete metal item (previous version) | Count | Replaced by |
|---|---|---|
| Pivot screws / metal dowels (2 drive axles + 2 follower axles + 4 finger pins) | 8 × A4/316 SS | **8 printed heat-stake pins + 8 printed melt caps** — 4 axle pins (`pin_A_R/A_L/B_R/B_L` = `melt_pin_axle`) + 4 finger pins (`pin_C_R/C_L` = `melt_pin_finger_C`, `pin_D_R/D_L` = `melt_pin_finger_D`), each retained by a melted-on `melt_cap` |
| Nylon-insert locknuts (one per pivot) | 8 × SS | **Eliminated** — every pin is retained by its own melted-on cap (a thermal rivet head wider than the bore) |
| M3 front-cover screws | 4 × A4/316 SS | **4 integral printed cantilever snap clips** on `front_cover` |
| Input-shaft plain bushing (PTFE/acetal) | 1 | **Eliminated** — vertical input shaft runs in two flooded printed journal bores (no metal bushing); collar trapped geometrically in housing pocket |
| **Total bought hardware** | **19 pieces** | **0 pieces** |

---

## 3. The input shaft runs in flooded printed journal bores (no bushing)

The input shaft is a **separate printed part (`input_pinion_shaft`)** that
exits through the housing **bottom wall**. In this flooded design it turns in
**two plain printed journal bores** in the housing — no metal bushing. The bore
radius (`SHAFT_R_BORE = 4.3 mm`) clears the Ø8 mm shaft (`SHAFT_R = 4.0 mm`)
with a running fit.

- **Upper journal** (alignment, near the pinion): 2.0 mm long, in a boss
  standing up from the inside of the bottom wall.
- **Lower journal** (load-bearing exit): 7.0 mm long, through the bottom wall
  and mounting flange.
- **Collar axial capture**: an integral collar (OD 5.8 mm, length 2.0 mm) on
  the shaft sits in a pocket between the two bore-mouth shoulders — wider than
  the bore, trapped with ~0.25 mm axial play each side. This is **rigid
  geometric capture** (a formed shoulder wider than the bore, same family of
  retention as the melt-capped pin heads), not elastic preload — no creep risk.

Flooded journal bores work for the same reason as the pivot bores: no pressure
differential, no dry cavity — the joint runs wet, water is coolant and
lubricant. A sealed bearing traps grit; an Oilite bushing leaches oil when
flooded. Printed bores flush clean with a fresh-water rinse.

---

## 4. User-supplied items (outside the gripper BOM)

| Item | Qty | Notes |
|---|---|---|
| Waterproof actuator (force-sensing) | 1 | Couples to the **bottom D-profile coupler** on `input_pinion_shaft` (radius 5.0 mm, D-flat 1.4 mm, length 12 mm) via a printed adapter horn. **Selected primary: a smart serial-bus servo — DYNAMIXEL XW540-T260-R** ([buy: ROBOTIS US store, USD 1,241.89 ≈ AUD 1,925](https://robotis.us/dynamixel-xw540-t260-r/), verified May 2026; `-R` = RS-485) — IP68 body, ~1.9 N·m, native `present_current` telemetry, chosen because the actuator doubles as the **grip-force sensor** (motor current → tip force; no fingertip electronics). **Value alternative — just as good for ≤ $500: DYNAMIXEL XM540-W270-R** ([buy: ROBOTIS US store, USD 494.39 ≈ AUD 766](https://robotis.us/dynamixel-xm540-w270-r/), verified May 2026) — same Dynamixel-X RS-485 bus + identical `present_current` telemetry, *more* torque (cont 2.12 / stall 10.6 N·m), drop-in; only lacks the IP68 body, which is moot at T2 (canister needed either way). **Deep-budget alternative: Feetech STS3250** ([buy: OpenELAB, €63.85 ≈ AUD 110, in stock](https://openelab.io/products/feetech-sts3250-c002-servo-12v), May 2026) — 50 kg·cm / 4.9 N·m stall @ 12V (sustained ~2.45 N·m after torque-protection, still well above the 1.2 N·m floor), TTL half-duplex serial with `load / position / voltage / temperature` feedback (load % is the torque proxy, calibrated like Dynamixel `present_current`); plastic case, no IP rating → canister required. **Rock-bottom: Feetech STS3215 (C018, 12 V)** ([buy: eckstein-shop.de, €26.45 ≈ AUD 44](https://eckstein-shop.de/feetech-st-3215-c018-servo-en), May 2026) — same SCS bus + load feedback, smaller motor at 30 kg·cm / 2.94 N·m stall and ~0.98 N·m continuous (below the 1.2 target, above the 0.6 floor — adequate for intermittent mid-face grip-and-hold, not sustained tip clamping). **Tier-3 (>30 m) fallback: a magnetic-coupling dry-pod drive** (no shaft penetration). T2 (≤30 m) still needs a thin pressure canister. The actuator's firmware **current limit must be set to the gear ceiling `T_safe`** (gear protection). Full selection + sourcing: `motor/SELECTION.md` / `motor/SURVEY.md`; sensing: `motor/SENSING.md`; see also `UNDERWATER.md` §6. |
| **Pressure canister assembly for the actuator** (T1–T3) | 1 | Houses the chosen actuator (XW540 / XM540 / STS3250 / STS3215) for any non-trivially-wet deployment — **T2 (≤ 30 m) needs a canister even for the IP68 XW540** (IP68 = 1 m freshwater only). Full architecture in `motor/ROV_INTEGRATION.md` §2c–§2d. **Itemised kit** (Blue Robotics 3" locking series + a standard 8 mm lip seal — the de-facto small-ROV recipe): <br><br>**Tube:** [3" cast-acrylic locking tube, 240 mm length, 150 m depth rating — Part `BR-102649-240`](https://bluerobotics.com/store/watertight-enclosures/locking-series/wte-locking-tube-r1-vp/) — **USD 25**. Fits the longest servo body (~117 mm XW540/XM540) + connector bend; ≥ 5× depth margin at T2. *Upgrade for sustained service:* same-series **aluminium tube** (1000 m rated, ~USD 100+) — acrylic is Blue-Robotics-rated for short-term immersion (< ~2 weeks). <br><br>**Wet-side end cap (shaft exit):** [Blue Robotics 3" aluminium end cap, "blank" SKU = no factory holes as shipped — Part `BR-100949-999`](https://bluerobotics.com/store/watertight-enclosures/locking-series/wte-end-cap-vp/) — **USD 34**, 1000 m rated. **Drilled in build to Ø14 H7 centre-bore** (light press-fit, no adhesive) for the lip seal per `motor/ROV_INTEGRATION.md` §2d Option A. <br><br>**Dry-side end cap (cable exit):** [Blue Robotics 3" aluminium end cap with 4 × M10 factory penetrator holes — Part `BR-100949-004`](https://bluerobotics.com/store/watertight-enclosures/locking-series/wte-end-cap-vp/) — **USD 34**, 1000 m rated. <br><br>**Cable penetrators (dry-side cap):** [Blue Robotics WetLink Penetrator](https://bluerobotics.com/store/cables-connectors/penetrators/wetlink-penetrator/) — **~USD 13 each, qty 2** (one for the bus + power, one spare/vent). <br><br>**Unused-hole plugs (dry-side cap):** [Blue Robotics WetLink Penetrator Blank M10](https://bluerobotics.com/store/cables-connectors/wlp-blank/) — **USD 5–8 each, qty 2** (plugs the remaining 2 M10 holes on `BR-100949-004`; 1000 m rated). <br><br>**Shaft seal (the actual shaft-exit waterproofing — Option A per §2d):** Single-lip NBR radial shaft seal, **8 × 14 × 4 mm, DIN 3760 Type A** (standard size, multiple manufacturers; SKF CR HMS5 is the premium reference). Buyable: [EAI Oil Seal 8×14×4 SC NBR with garter spring (Amazon)](https://www.amazon.com/8X14X4-Grease-EAI-Spring-8mmx14mmx4mm/dp/B07NKXB2VL) — **~USD 5**. *Upgrade for higher pressure / chemical / cold-water service:* SKF CR 8×14×6 HMSA7 V Viton dual-lip, ~USD 12–15. <br><br>**Adapter shaft (Ø 8 mm, precision-ground stainless, the part the lip seal runs on):** [goBILDA 2100 Series Stainless Steel Round Shaft, 8 mm × 50 mm](https://www.gobilda.com/2100-series-stainless-steel-round-shaft-8mm-diameter-50mm-length/) — **USD 2.79**. *In build:* the dry end clamps to the servo horn via a small printed adapter (per actuator's horn pattern — printed in PA12-GF or PETG-HF, no buy); the wet end carries a printed/machined D-socket matching the gripper's input D-coupler (Ø10 / D-flat 1.4 mm / 12 mm engagement). For best seal life, polish the lip-contact band of the goBILDA shaft to Ra ≤ 0.4 µm (5 min on a polishing wheel; goBILDA ships at Ra ~0.4–0.8 µm — usable as-is for first integration). <br><br>**Assembled total ≈ USD 130 (≈ AUD 200)** for the acrylic + standard-seal build at T2. <br><br>**For Tier 3 (>30 m), swap Option A → Option B per `motor/ROV_INTEGRATION.md` §2d Option B**: replaces the wet-side end cap + lip seal + adapter shaft with a **thin non-conductive end cap** (printed PETG/PA12-GF or machined PEEK) + **inner-rotor magnet** on the servo + **outer-rotor magnet + 608ZZ bearing** on the wet side. Same canister tube + dry-side cap + penetrators. Coupling: KTR MINEX-S SA 60/8 (~USD 600–800 quote) or DIY 80 mm N52 ring (~USD 15–50). |
| M4 bolts (robot-arm mount) | 4 | Attach the **bottom flange** to your robot arm or mount. The flange carries 4 × M4 clearance holes positioned around (but clear of) the shaft exit. These are **arm hardware, not gripper hardware** — choose grade and length to suit your arm. If the arm is metal, add nylon or PTFE shoulder bushings + isolating washers at each bolt (see `UNDERWATER.md` §5). The gripper itself contributes no metal to this joint. |
| **Mounting interface adapter** (optional, printed) | 1 | Choose an adapter that mates the gripper's 4×M4 bottom flange to your specific arm or chassis. **Printed PA12-GF, all parametric build123d** under `motor/cad/adapters/`. **Seven options** modelled (`motor/cad/output/adapter_*.step`): **P0 (ready now)** — `adapter_bravo7` (Reach Bravo 7 RB-1054, Ø71/6×M6+6×M5 CSK, ~50 g), `adapter_iso9409_50_4_M6` (UR/Franka/Doosan/Fanuc CRX cobot flange, Ø63/4×M6, **dry only**, ~40 g), `adapter_br2_bottom_newton` (BlueROV2 Newton-footprint 2×M5/100 mm/**16° tilt**, ~24 g). **P1 variants** — `adapter_iso9409_80_6_M8` (UR20-class cobots, Ø100/6×M8, **dry only**, ~80 g), `adapter_br2_roof_rack` (BR2 front-mount L-bracket, ~300 g), `adapter_br2_payload_skid` (BR2 payload skid, ~50 g). **P2 held-tool** — `adapter_iso13628_d_handle` (ISO 13628-8 / API 17H Class A D-handle for Schilling/Kraft/ECA/Hydro-Lek work-class arms — the arm's existing standard jaws clamp the handle, no bolt-on, ~107 g). Full comparison + open questions: [`motor/INTERFACES.md`](../motor/INTERFACES.md); per-interface dossiers: `motor/interfaces/*.md`. |
| **Power-supply chain** (per-interface) | 1 chain | The XW540 wants **12 V / ≤ 6 A peak**; no real-arm wrist can supply that directly, so a step-down regulator + fuses + connector chain is required between the upstream bus and the canister. **Full breakdown:** [`motor/POWER_SUPPLY.md`](../motor/POWER_SUPPLY.md) §8 (POW-1 to POW-11, each line cited to a vendor SKU). **Recommended primary chain:** Pololu D36V50F12 12 V/6.5 A buck (\#4095, USD 39.95) + 8 A ATO inline fuse + 10 A polyfuse backstop + SMBJ16A TVS (**mandatory** P2 gear-protection) + AWG 16 marine-grade twisted pair + BR WetLink penetrator + Robotis 4-pin X4P cable + Robotis U2D2 USB-RS485 master (USD 36.92). **Incremental cost by interface:** BR2 chassis ~USD 50–65 · cobot bench ~USD 95 · Reach Bravo ~USD 365–565 · Schilling/Kraft ~USD 245. **Critical safety:** **never connect the BR2 14.8 V Li-ion battery directly to the XW540** — full-charge is 16.8 V, exceeds the 14.8 V max servo rating; the buck is mandatory, not optional. |

---

## 5. Printed-part count summary

| Group | Qty | Material (FINAL) |
|---|---|---|
| `enclosure` | 1 | PA12-GF |
| `front_cover` (4 integral clips + 3 vent holes) | 1 | PA12-GF |
| `drive_arm_R` | 1 | PA12-GF |
| `drive_arm_L` (integral crown gear; rides on `pin_A_L`) | 1 | PA12-GF |
| `input_pinion_shaft` (pinion + shaft + collar + D-coupler) | 1 | PA12-GF |
| `follower_R` | 1 | PA12-GF |
| `follower_L` | 1 | PA12-GF |
| `finger_R` | 1 | Ether-based TPU ~95A |
| `finger_L` | 1 | Ether-based TPU ~95A |
| `pin_A_R` (axle pin, `melt_pin_axle` ★) | 1 | **PETG-HF** |
| `pin_A_L` (axle pin, `melt_pin_axle` — new ★) | 1 | **PETG-HF** |
| `pin_B_R` (axle pin, `melt_pin_axle` ★) | 1 | **PETG-HF** |
| `pin_B_L` (axle pin, `melt_pin_axle` ★) | 1 | **PETG-HF** |
| `pin_C_R` (finger pin, `melt_pin_finger_C` — LONG ★) | 1 | **PETG-HF** |
| `pin_D_R` (finger pin, `melt_pin_finger_D` — SHORT ★) | 1 | **PETG-HF** |
| `pin_C_L` (finger pin, `melt_pin_finger_C` — LONG ★) | 1 | **PETG-HF** |
| `pin_D_L` (finger pin, `melt_pin_finger_D` — SHORT ★) | 1 | **PETG-HF** |
| `melt_cap` (heat-stake cap, one per pin ★) | 8 | **PETG-HF** |
| **Total printed parts** | **25** (9 structural + 8 pins + 8 caps) | — |
| Bought hardware inside gripper (screws/nuts/bolts/bushings) | **0** | — |
| User-supplied (outside gripper) | Waterproof actuator + D-shaft coupling; M4 flange bolts + nylon/PTFE galvanic-isolating washers | — |

★ All 8 pins + 8 melt caps in PETG-HF (final build) so they heat-stake cleanly — see §1.2 rationale.

---

## 6. Why fully-printed is corrosion-proof underwater

A gripper made **entirely of polymer** has **no galvanic cell anywhere** —
and galvanic corrosion is the primary failure mode of mixed-metal hardware in
seawater. The previous version maintained all metal in one stainless family
(316/A4) to avoid an internal galvanic pair; this revision deletes the problem
at the root by deleting the metal.

With no screws, nuts, bolts, pins, or bushings inside the gripper:

- **No dissimilar-metal contact, no anode, no pitting, nothing to rust.**
- Structural parts in PA12-GF: low water uptake (~0.7–1.2 % saturated, further
  reduced by glass fill), no hydrolysis, holds dimension over months of immersion.
- `input_pinion_shaft` in PA12-GF: rigid collar-capture geometry, low creep —
  retention stays positive with zero elastic degradation.
- All 8 pivot pins + 8 melt caps in PETG-HF: low uptake (~0.1–0.3 %), retained by
  a melted-on rivet head (geometric, nothing flexes). PETG-HF chosen because it
  heat-stakes cleanly; glass-filled PA12-GF does not.
- Fingers in ether-based TPU: does not hydrolyze in sustained immersion.
- Housing flooded: internal and external pressure equalize through drain holes
  and vent holes — the thin printed wall sees no differential, nothing to crush.
- Input shaft runs in flooded journal bores: flushes clean, no sealed race to
  trap grit, no Oilite to leach oil, no seal to fail.

**Net: nothing to rust, nothing to seal, nothing to crush, and nothing to buy
inside the gripper — rinse with fresh water after each salt dive.**

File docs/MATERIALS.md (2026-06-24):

# Material-specific validation — pinned material plan

Final material-engineering gate for the fully-3D-printed underwater gripper
(`gripper.py`). The structural snap-fits in this design were geometry-tuned for
**ductile PETG** (insertion strains sit comfortably under PETG's elastic band).
The user has now **pinned the production material to glass-filled Nylon 12
(PA12-GF)** for everything rigid. PA12-GF is stiffer and markedly more brittle
(lower elongation-at-break), so this document re-checks every snap against the
*real* allowable strain of PA12-GF, not PETG's.

> **Headline verdict (RESOLVED — production-ready):** The body and arms are FINE
> in PA12-GF. The pivot pins are no longer flexing snaps at all — they are
> **heat-stake (melt-rivet) pins**: plain PETG-HF journal pins each retained by a
> separate PETG-HF cap (`melt_cap`) melted over the protruding stud with a
> soldering iron. Retention is a formed head wider than the bore (geometric);
> nothing flexes, so the old insertion-strain check on the finger pins is moot.
> The one remaining **flexing** snap is the **cover clip**, originally tuned to
> PETG's elastic band; it did NOT clear PA12-GF's allowable strain as drawn and is
> now fixed in `gripper.py` (verified, interference CLEAN all poses):**
> - Cover clip: `SNAP_Z0` changed 6.5 → 1.5 (cantilever lengthened) and arm
>   `SNAP_ARM_T` thinned 2.8 → 2.0 mm → worst-tight strain 3.32 % → **1.36 %**
>   (1.07 % nominal), inside PA12-GF allowable. **PASS.**
> - Pivot pins (all 8) + caps: PETG-HF, heat-staked. PETG-HF chosen because it
>   **melts cleanly under a soldering iron** — glass-filled PA12-GF does not
>   heat-stake well. Retention is the formed rivet head, not an elastic snap, so
>   there is no insertion-strain gate to clear. **PASS.**
> - Closed-pose pin collision: `THETA_CLOSED` 104 → 102°, pin gap ~9.86 mm, no
>   interference. **PASS.**
> - Pin retention: melt-cap rivet head bears on the rigid PA12-GF eye / back-wall
>   face (the old counterbore capture pockets are gone with the heat-stake
>   redesign). **PASS.**
>
> **No remaining FAILs. Design is production-ready. A printed coupon fit-test in
> real materials is still recommended before the full production run (§5/§8).**
> Buoyancy, water-swell, and galvanic all PASS (unchanged).

All strain numbers below are the cantilever surface-strain estimates from
`ENGAGEMENT.md` (and re-derived from `gripper.py` constants — see §2). They are
**order-of-magnitude per the snap-fit engineer's own caveat**; the binding gate
is a printed coupon in *actual PA12-GF* (§5, §8).

---

## 1. Mechanical properties used (FDM-printed, typical published ranges)

Printed (FFF) values, not datasheet injection-moulded values — FFF parts run
~10–30 % below moulded due to inter-layer adhesion and porosity. Ranges are
typical of commercial filament datasheets (e.g. 3DXTech/Polymaker/BASF
PA12-GF/PAHT-GF grades; generic PETG; generic ether-TPU 95A) plus the standard
snap-fit design literature (Bayer/Covestro *Snap-Fit Joints for Plastics*; BASF
and DuPont equivalent guides). Cite-on-coupon: confirm against your actual spool.

| Property (FFF print) | **PA12-GF** (final) | **PETG-HF** (test) | **Bambu TPU 95A HF** (fingers) |
|---|---|---|---|
| Tensile modulus E | **3.5–5.5 GPa** (glass-stiffened) | ~1.7–2.1 GPa | **9.8 MPa (X-Y) / 7.4 MPa (Z)** — MEASURED, ISO 527 printed, anisotropic |
| Flexural modulus | **4–6 GPa** | ~1.9–2.3 GPa | N/A (Bambu TDS; compliant) |
| Tensile / yield strength | **40–70 MPa** (filled, often no yield plateau — fails near-brittle) | ~40–50 MPa | **27.3 MPa (X-Y) / 22.3 MPa (Z)** (ISO 527 printed; elastomer, not a brittle yield) |
| **Elongation at break** | **~3–8 %** (printed GF nylon; brittle) | ~6–12 % | **>650 % (X-Y) / >480 % (Z)** (elastomer) |
| **Allowable design strain, one-time snap** (~0.5–0.7× ε_break for filled) | **~1.5–2.0 %** | **~2.5–3.5 %** | n/a (elastic, not snap) |
| Water absorption (saturated immersion) | **~0.7–1.2 %** (PA12 is the lowest-uptake nylon; glass fill lowers it further) | ~0.1–0.3 % (low) | **1.08 %** (ISO, 25 °C/55 % RH) |
| Density ρ | **~1.20–1.30 g/cc** | ~1.27 g/cc | **1.22 g/cc** (ISO 1183) |
| Creep | low–moderate (glass fill greatly improves over unfilled nylon) | moderate | **high (creeps)** — never structural |

Key facts that drive this review:

- **Glass fill trades ductility for stiffness.** Unfilled PA12 prints at
  ~10–20 % elongation; **30 % glass-filled drops it to ~3–8 %** and removes the
  yield plateau — the part snaps rather than yields. This is the whole reason
  the PETG-tuned snaps need re-checking.
- **PETG-HF ("high-flow") ≈ PETG mechanically.** High-flow is a *processing*
  variant (lower melt viscosity, faster printing); modulus, strength and
  elongation are within normal PETG scatter. Strain allowables transfer.
- **PA12 is the *least* hygroscopic nylon.** Do not conflate it with PA6/PA66
  ("nylon swells in water"). Saturated uptake ~1 %, and glass fill cuts it more.
  This matters for §4.

---

## 2. SNAP-FIT STRAIN VALIDATION (the critical check)

**Strain model** (same one `ENGAGEMENT.md` uses): cantilever surface strain
`ε = 3·t·δ / (2·L²)`, where `t` = beam bending thickness, `δ` = insertion
deflection, `L` = free cantilever length. **Allowable** = the material's
one-time-assembly design strain from §1.

### 2a. Re-derivation from `gripper.py` (confirms ENGAGEMENT.md)

**Cover clip** (`_one_clip` / `_all_snap_clips`): arm thickness
`t = SNAP_ARM_T = 2.0 mm` (thinned from 2.8); insertion deflection = the hook must
ride out by `SNAP_HOOK_ENGAGE = 1.5 mm` (nominal) → 1.9 mm worst-tight (+0.2 FDM
each side); free length `L = COVER_Z[0] − SNAP_Z0 = 20.5 mm`.
ε = 3·2.0·1.9/(2·20.5²) = **1.36 %** worst-tight (**1.07 %** nominal at δ=1.5).
✔ matches ENGAGEMENT.md. **Build-time gate:** `gripper.py` now asserts the
worst-tight strain stays under the conservative 1.5 % PA12-GF ceiling
(`SNAP_STRAIN_ALLOW = 0.015`) and fails the build loud if it does not.

**Pivot pins** (`melt_pin_axle`, `melt_pin_finger_C`, `melt_pin_finger_D`): **no
cantilever strain check applies.** These are heat-stake pins — plain journal pins
retained by a separate `melt_cap` melted over the protruding stud. Nothing flexes
on insertion; retention is the formed rivet head (geometric). The old finger-pin
barb strain derivation (the ~2.50 / 2.78 % split-collet numbers, and the
`SNAP_SLOT_LEN` model caveat) is **obsolete** — there is no barb and no flexing
collet. The only material requirement on the pins is that they **heat-stake
cleanly** (→ PETG-HF, not glass-filled PA12-GF; see §3).

### 2b. Allowable vs measured — PASS / MARGINAL / FAIL

Allowables: **PA12-GF ε_allow ≈ 1.5–2.0 %** (one-time assembly, filled grade,
no yield plateau → ~0.5× of a ~3–8 % ε_break). **PETG-HF ε_allow ≈ 2.5–3.5 %.**
The Bayer/Covestro guide quotes filled-nylon one-time-assembly allowables as high
as ~2.5–3 % for tougher grades; **we deliberately use the conservative 1.5–2.0 %
end** because a brittle filled nylon with no yield plateau fails by cracking, not
by forgiving plastic deformation — the consequence of being wrong is a shed cover
or a cracked pin, so the margin is taken on purpose, not by recall.

> ### A. FINDINGS TABLE — each snap × {PA12-GF, PETG-HF} — **UPDATED: reflects fixes applied**
>
> | Snap feature | Insertion strain (nom / worst-tight) | **PA12-GF** (allow ~1.5–2.0 %) | **PETG-HF** (allow ~2.5–3.5 %) | Status |
> |---|---|---|---|---|
> | **Cover clip** (`_one_clip`) — *as drawn* | 2.62 % / **3.32 %** | ~~FAIL~~ — worst-tight 3.32 % > 2.0 % ceiling | PASS — firm click | **FIXED** |
> | **Cover clip** (`_one_clip`) — *after `SNAP_Z0` 6.5→1.5 + arm thinned 2.8→2.0* | **1.07 % / 1.36 %** | **PASS — both nominal (1.07 %) and worst-tight (1.36 %) inside allowable, under the 1.5 % build gate** | PASS | **PASS** (resolved) |
> | **Finger pins** (`melt_pin_finger_C/D`) — *heat-stake* | n/a — **no flexure** (melt-rivet head, geometric capture) | N/A — pins are PETG-HF (must melt under a soldering iron; PA12-GF heat-stakes poorly) | **PASS — formed-head retention, no strain gate** | **PASS** (resolved by heat-stake redesign) |
> | **Axle pins** (`melt_pin_axle`) — *heat-stake* | n/a — **no flexure** (melt-rivet head through the back-wall flood hole, geometric capture) | N/A — PETG-HF (must melt; PA12-GF heat-stakes poorly) | **PASS — riveted to the back wall** | **PASS** (resolved) |
> | **Melt cap seat** (`melt_cap`, formed head vs eye/wall face) | n/a — static bearing, not a flex | **PASS** (rigid PA12-GF eye face is the bearing surface) | **PASS** | PASS (confirmed) |
>
> **All retention features now PASS.** The cover clip — the only remaining flexing
> snap — passes in PA12-GF with the lengthened cantilever (`SNAP_Z0=1.5`). All 8
> pivot pins + caps are heat-staked in PETG-HF (PETG-HF chosen so they melt cleanly
> under a soldering iron; glass-filled PA12-GF does not heat-stake well); their
> retention is a formed rivet head, geometric, so there is no insertion-strain gate
> to clear. The pull-out bearing face is the rigid PA12-GF eye / back wall.

**Why FAIL not just MARGINAL for the cover clip:** even the *nominal* 2.62 %
sits above the 2.0 % PA12-GF ceiling, and the worst-tight 3.32 % is at the very
edge of PA12-GF's *break* strain (~3–8 %, low end). A brittle filled-nylon clip
flexed to its break strain on every assembly will micro-crack at the hook root
and shed the cover. This must be fixed before the PA12-GF print.

**Second-order effect (note for the assembler):** swapping PETG→PA12-GF at
*identical geometry* leaves ε unchanged (geometry-only) but **insertion force
roughly doubles** (E ~2 → ~4 GPa). A clip that's a firm hand-click in PETG-HF
can need tooling in PA12-GF — another reason to lengthen the arm (lower force
*and* lower strain).

---

## 3. Fix summary (full constants in the delimited section at the end)

- **Cover clip — CLEAN top-level fix.** Lengthen the cantilever
  (**`SNAP_Z0 = 6.5 → 1.5`**, drop the arm root 5 mm down the outer wall, L 15.5
  → ~20.5) **and thin the arm `SNAP_ARM_T = 2.8 → 2.0 mm`** (outward tab
  protrusion 3.2 → 2.4 mm, sleeker blade-like tab; still ≥ the 1.5 mm functional
  wall floor). Strain is *linear* in thickness, so thinning the arm LOWERED the
  strain → worst-tight **1.90 % → 1.36 %** (1.07 % nominal) → **more PA12-GF
  margin, not less**, still **inside the conservative PA12-GF ~1.5–2.0 %
  allowable and under the new 1.5 % build-time gate → true PASS** (vs hard FAIL
  before), still PASS/firm in PETG-HF. Verified collision-free: the arm runs on
  the outer X side wall at Z 1.5–22; the back flange is at Z −16…−6 and the
  cavity floor far away — no clash, hook/window/engagement unchanged (engagement
  stays 1.5 mm nominal / 1.10 mm worst-loose ✔). **Bonus:** bending stiffness
  goes as t³, so thinning the arm drops it to ~(2.0/2.8)³ ≈ 0.36× the previous
  (lengthened) clip — net insertion force ≈ **0.31×** of the old PETG clip, a
  noticeably softer, lighter tactile click that is easier to seat by hand, while
  **retention is unchanged** (it is the geometric 1.15 mm hook-in-window
  engagement that holds the cover, not the spring force).
- **Pivot pins — redesigned as heat-stake (melt-rivet) pins; no strain knob at all.**
  All 8 pins (`melt_pin_axle` ×4, `melt_pin_finger_C` ×2, `melt_pin_finger_D` ×2)
  are plain PETG-HF journal pins, each retained by a separate PETG-HF `melt_cap`
  melted over the protruding stud with a soldering iron → a thermal rivet head
  wider than the bore. Nothing flexes, so there is no insertion-strain gate and the
  old barb fix-options (per-part material exception, or deepening the slot floor in
  `snap_pin()`) are moot. **PETG-HF is required** for the pins *and* caps because
  glass-filled PA12-GF does not heat-stake cleanly under a soldering iron. Finger
  pins are now **two SKUs** (LONG `_finger_C` at the crank layer, SHORT `_finger_D`
  at the follower layer) because C and D sit at different Z depths. Pins are
  ~1 g each, caps <1 g each (buoyancy-irrelevant).

---
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

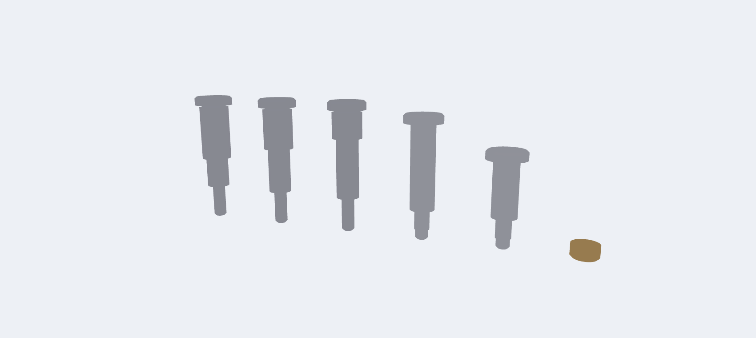
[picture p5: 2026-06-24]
renders/gripper_pins_parts.png

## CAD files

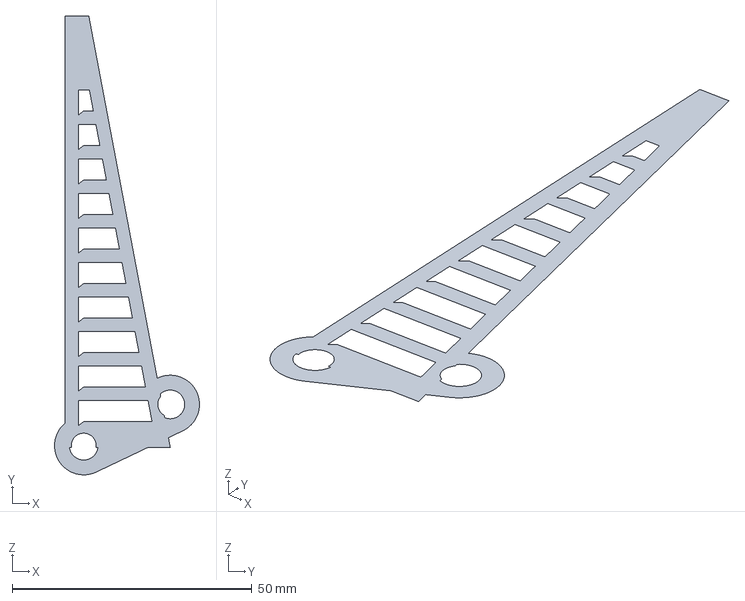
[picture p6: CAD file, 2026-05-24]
fea/iterations/diag_smallmid/section.step
30.2 x 95.7 x 0 mm

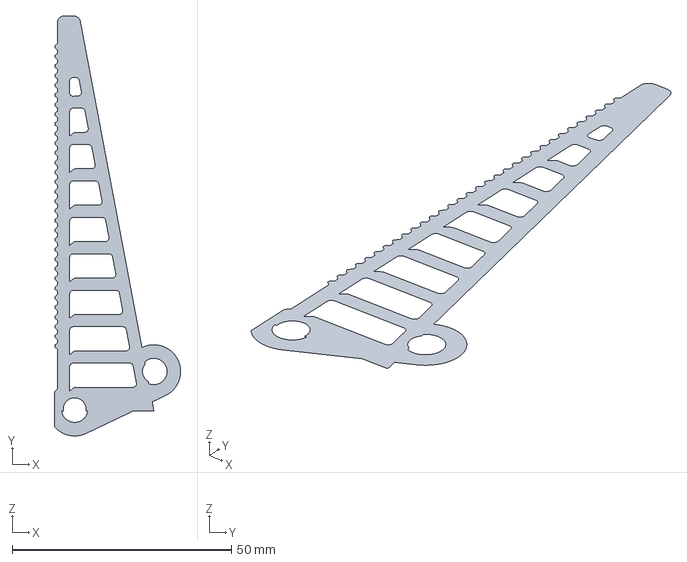
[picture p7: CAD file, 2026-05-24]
fea/iterations/iter00b_targetgrip/section.step
28.8 x 95.7 x 0 mm

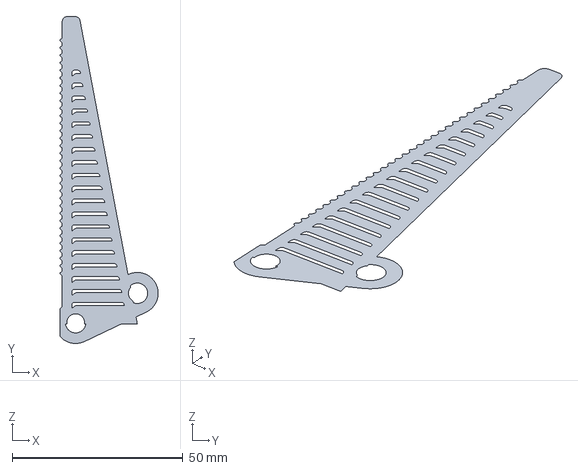
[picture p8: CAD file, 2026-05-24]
fea/iterations/r1_ribs22/section.step
28.8 x 95.7 x 0 mm

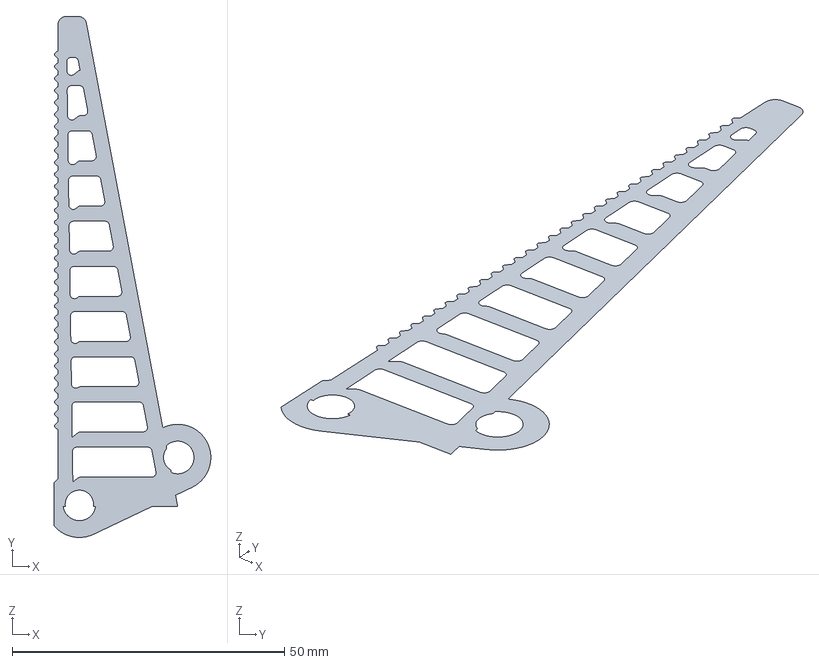
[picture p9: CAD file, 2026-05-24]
fea/iterations/w1_contactgrad15/section.step
28.8 x 95.7 x 0 mm

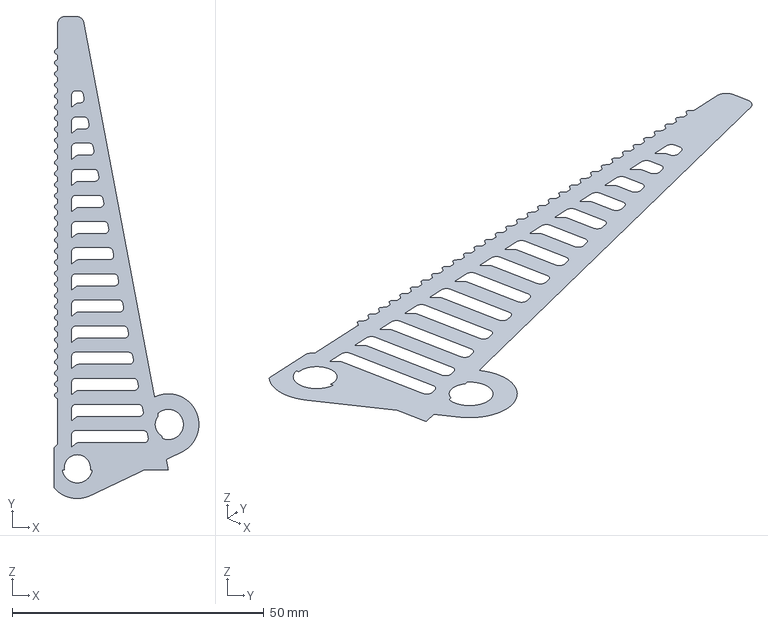
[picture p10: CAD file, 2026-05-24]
fea/iterations/w2_ribs16/section.step
28.8 x 95.7 x 0 mm

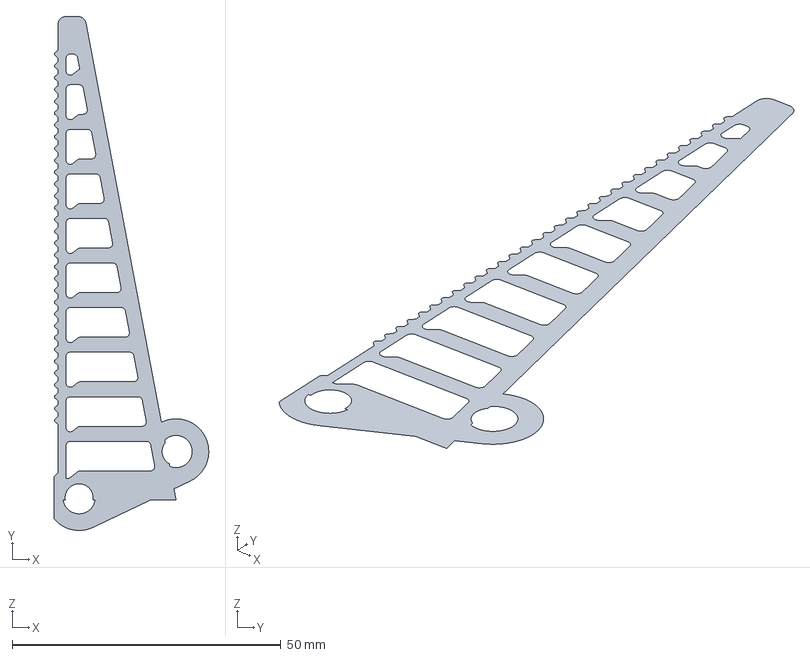
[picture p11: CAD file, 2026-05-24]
fea/iterations/w4_csoft15/section.step
28.8 x 95.7 x 0 mm

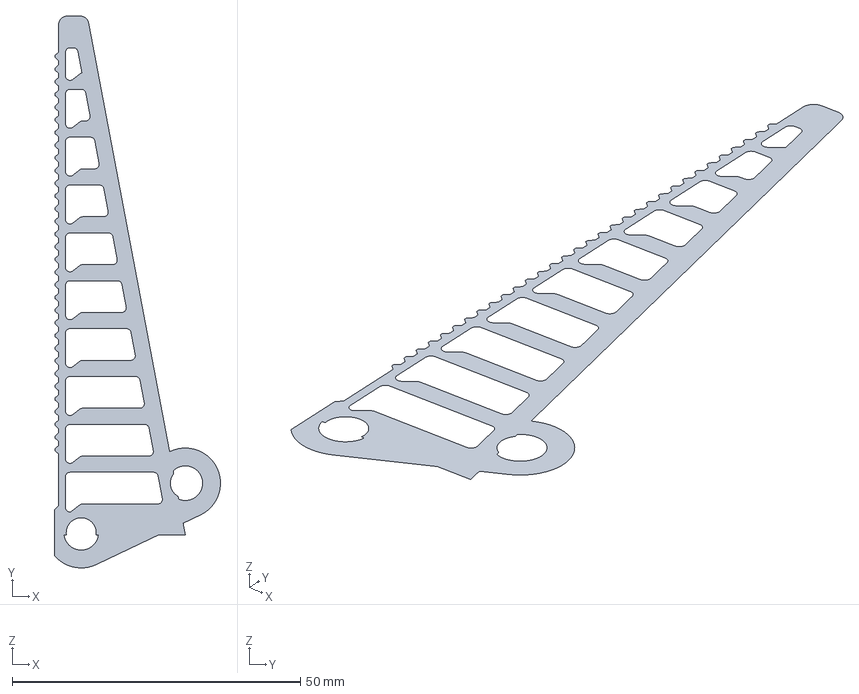
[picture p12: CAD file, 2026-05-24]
fea/iterations/w5_csoft12/section.step
28.8 x 95.7 x 0 mm

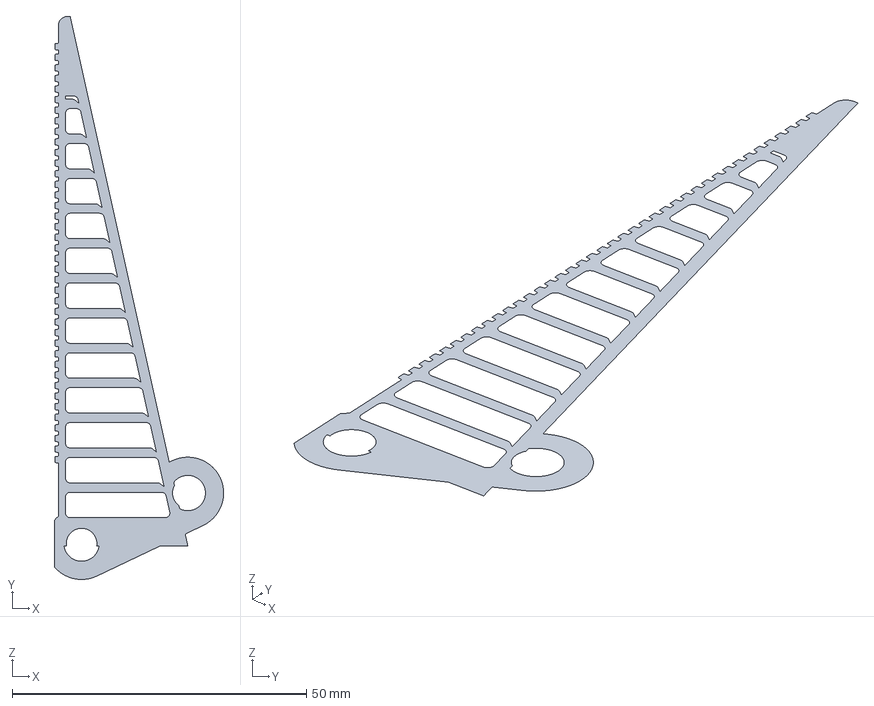
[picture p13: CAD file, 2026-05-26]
fea/scripts/finger_section.step
28.8 x 95.7 x 0 mm

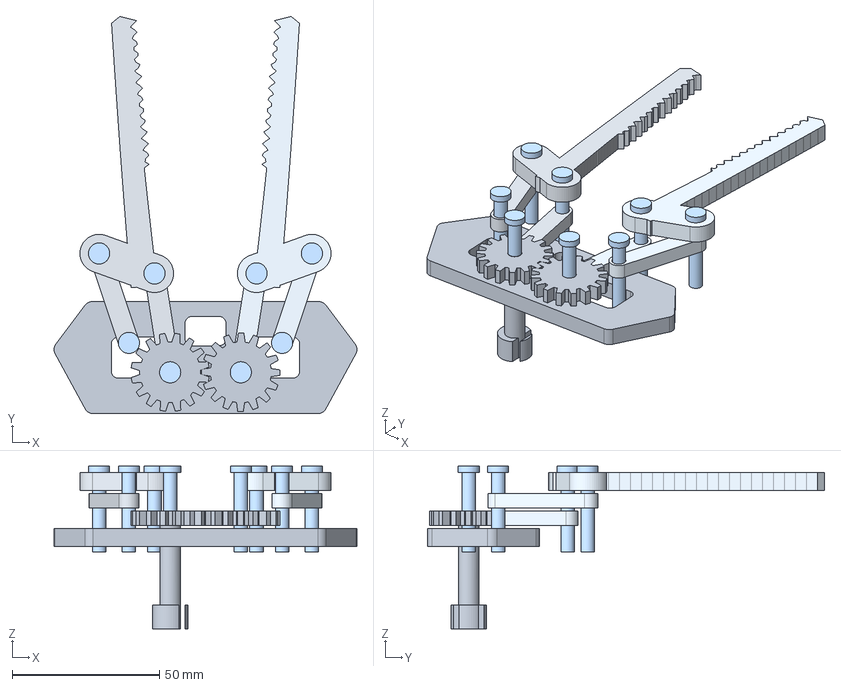
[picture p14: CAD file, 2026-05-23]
gripper_mid.step
102.9 x 134.8 x 55.2 mm
crank_R
crank_L
follower_R
follower_L
finger_R
finger_L
pin_A_R
pin_B_R
pin_C_R
pin_D_R
pin_A_L
pin_B_L
pin_C_L
pin_D_L

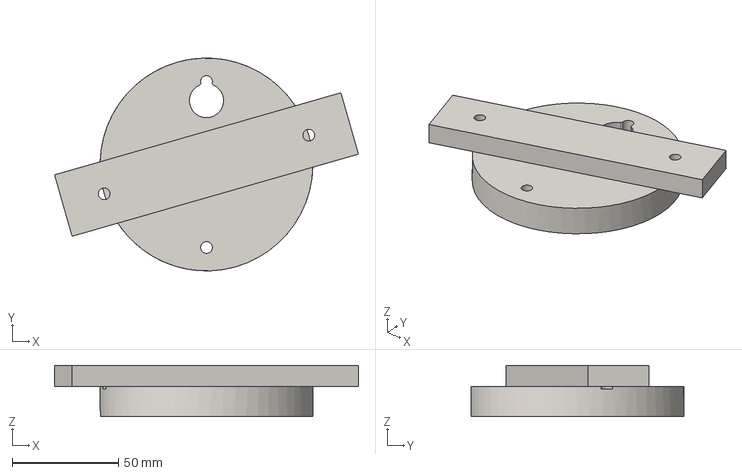
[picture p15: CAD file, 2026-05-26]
motor/cad/output/adapter_br2_payload_skid.step
142.8 x 100.0 x 24.0 mm

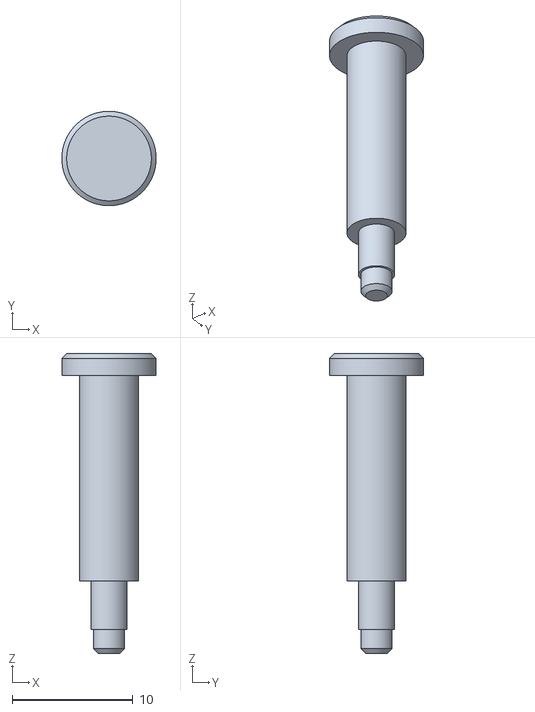
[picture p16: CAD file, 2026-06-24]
output/melt_pin_finger_C_x2_PETG-HF.stl
7.80 x 7.80 x 24.8

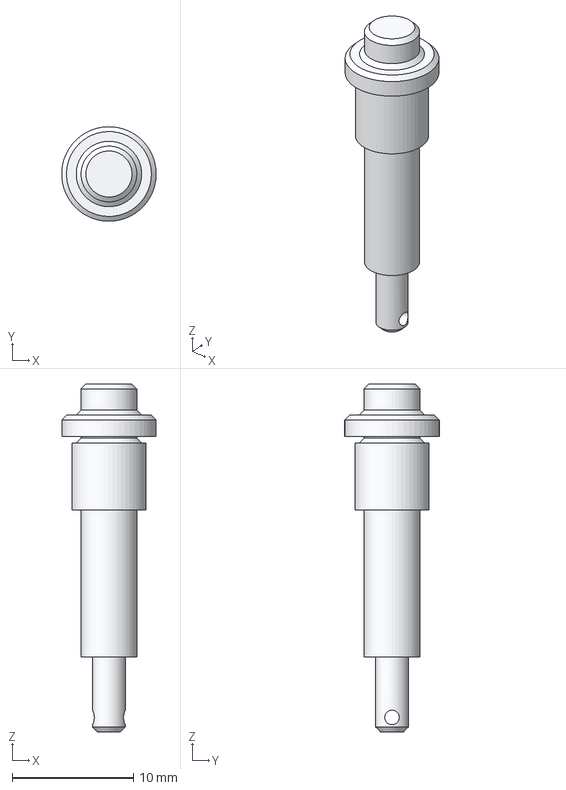
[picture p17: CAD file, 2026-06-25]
parts/melt_pin_axle_B.step
7.79 x 7.80 x 28.7 mm

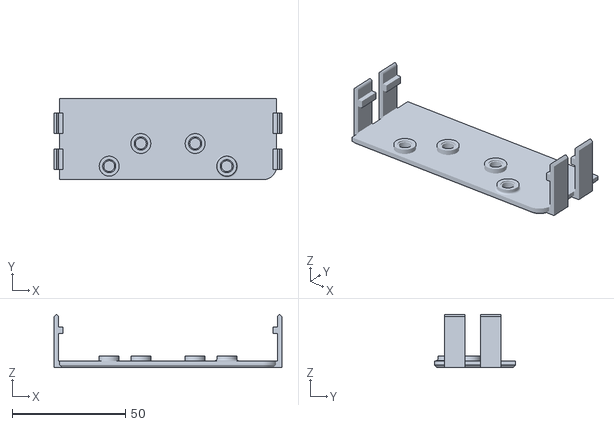
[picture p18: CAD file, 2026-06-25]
print_plates/oriented/front_cover.stl
100.8 x 36.0 x 23.5

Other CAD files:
fea/iterations/diag_smalltip/section.step
fea/iterations/w0_base/section.step
fea/iterations/w3_ribs16_cgrad/section.step
fea/iterations/w6_csoft_grad10/section.step
fea/iterations/w7_balanced/section.step
fea/iterations/exp_slantneg38/section.step
fea/iterations/exp_yc95/section.step
fea/iterations/f2_default/section.step
fea/iterations/f2_ribrev/section.step
fea/iterations/f2_ribsteep/section.step
fea/iterations/f2_symmetric/section.step
fea/iterations/iter00_baseline_correctBC/section.step
fea/iterations/r1_ribs16/section.step
fea/iterations/r1_slant22/section.step
fea/iterations/r1_tip10/section.step
fea/iterations/r1_tip16/section.step
fea/iterations/r1_tipcap05/section.step
fea/iterations/r1_wall15/section.step
fea/iterations/r1_wall20/section.step
fea/iterations/r2_spinetip10/section.step
fea/iterations/r2b_stiffbeam_thinrib/section.step
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

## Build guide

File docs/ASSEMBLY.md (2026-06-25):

# Assembly instructions — fully 3D-printed underwater gripper

> ## NO PURCHASED HARDWARE. ZERO FASTENERS. ONE TOOL (and only for 4 pins): a soldering iron.
> Every part of this gripper — including all 8 pivot pins, their 8 retainers, and
> the front cover — is **3D-printed**. No screws, no nuts, no metal dowels, no
> bearings, no bushings, no glue, no Allen keys. The **4 AXLE pins are CROSS-PINNED**
> — a printed `cotter` slips through a cross-bore behind the open back wall = a
> tool-free, removable, geometric pull-out stop (**no soldering iron**). The **4
> FINGER pins keep the heat-stake** cap (a separate printed cap fused onto the stud
> with a soldering iron), because their buried, grip-loaded studs have no clean
> external access. So the **only** tool the build needs is a **soldering iron, and
> only for the 4 finger pins**. Everything else slides, cross-pins, or snaps together
> by hand. (See `docs/PIN_RETENTION_ALTERNATIVES.md` for why the split.)

How to assemble the gripper entirely from printed parts (`gripper.py`) into a
working, single-DOF, **flooded underwater** gripper. Turn one input shaft and
**both jaws open/close symmetrically, splaying outward** as they open.

Read `PRINTING.md` for material, orientation, and post-processing first. Read
`UNDERWATER.md` for seawater material chemistry. This document assumes every
part is printed, deburred, and fit-tested.

Part names match `gripper.py` `gen_step()`: `enclosure`, `front_cover`,
`drive_arm_R`, `drive_arm_L`, `input_pinion_shaft`, `follower_R`, `follower_L`,
`finger_R`, `finger_L`. Pin SKUs: `melt_pin_axle` (×4), `melt_pin_finger_C`
(×2, the LONG crank-layer pin), `melt_pin_finger_D` (×2, the SHORT
follower-layer pin), and `melt_cap` (×8, one per pin). Pivots: **A_R, A_L**
(drive-arm axles), **B_R / B_L** (follower axles), **C_R, D_R, C_L, D_L**
(finger pins). The drive input enters via a right-angle crown + pinion stage
and exits the **housing bottom** — that bottom shaft-exit flange is the
mounting face, so the **back wall stays free and accessible** for melting the
axle caps from outside.

---

## Part inventory (25 printed parts, 0 hardware)

| Part label | Qty | Role |
|---|---|---|
| `enclosure` | 1 | Flooded gearbox housing, open front, bottom mounting flange |
| `front_cover` | 1 | Snap-on cover with 4 integral cantilever clips |
| `drive_arm_R` | 1 | Right gear sector + crank arm (rides on axle pin A_R) |
| `drive_arm_L` | 1 | Left gear sector + crank arm + **integral crown gear** (rides on axle pin A_L) |
| `input_pinion_shaft` | 1 | Vertical input shaft: pinion + continuous journal + bottom shoulder + D-coupler |
| `follower_R` | 1 | Right B→D link bar |
| `follower_L` | 1 | Left B→D link bar |
| `finger_R` | 1 | Right Fin Ray compliant jaw (TPU) |
| `finger_L` | 1 | Left Fin Ray compliant jaw (TPU) |
| `melt_pin_axle` (A_R, A_L, B_R, B_L) | 4 | **Cross-pinned axle pin** — journals an arm/follower; stud threads the back-wall flood hole, carries a transverse cross-bore retained by a cotter outside the back wall |
| `melt_pin_finger_C` (C_R, C_L) | 2 | **Heat-stake finger pin, LONG** — reaches the crank layer; capped at the crank-eye bottom on the bench |
| `melt_pin_finger_D` (D_R, D_L) | 2 | **Heat-stake finger pin, SHORT** — reaches the follower layer; capped at the follower-eye bottom on the bench |
| `cotter` | 4 | **Cross-pin** — a tiny straight rod slipped through each AXLE pin's cross-bore; a geometric pull-out stop wider than the bore. Tool-free, removable, **no soldering iron** |
| `melt_cap` | 4 | Separate retaining cap, one per FINGER pin — slips over the pin's melt-stud and is fused with a soldering iron into a thermal-rivet head wider than the bore |
| **Total** | **25** | **Zero purchased hardware** |

The finger pins are **two SKUs** because C and D sit at different Z depths: C
reaches the crank layer (the longer `melt_pin_finger_C`), D only reaches the
follower layer (the shorter `melt_pin_finger_D`). A single length would leave
half the finger pins unseated.

---

## How the pins work (read this before assembling)

All 8 pivot pins are **plain printed PETG-HF journal pins**, each retained by
a **separate printed PETG-HF cap** (`melt_cap`, ×8): you slip the cap over the
pin's protruding **melt-stud** and fuse it with a **soldering iron** into a
thermal-rivet head wider than the bore. Retention is **geometric** — a formed
head larger than the hole — **not** an elastic snap (nothing flexes, so
nothing breaks) and **not** a press fit (nothing relies on friction, so
nothing slides out). The 8 pins split into two families by *where* the cap is
melted, which drives the assembly order. Do not confuse them.

### Axle pins — `melt_pin_axle`: A_R, A_L, B_R, B_L (4 pins) — CROSS-PINNED

Plain headed journal pins. The **head seats just under the cover boss** (its
+Z stop); the **shank journals** the gear or follower eye and **bottoms on the
back-bore step** (its −Z stop); the **stud threads the back-wall flood hole and
protrudes past the EXTERIOR back face**, carrying a **transverse cross-bore**.

Retention is a **CROSS-PIN (cotter)** — *tool-free, geometric, removable* (the
2026-06 alternative to the heat-stake; `docs/PIN_RETENTION_ALTERNATIVES.md`).
Insert each axle pin from the open front (mechanism already in), flip the housing,
and **slip a printed `cotter` through the cross-bore** behind the back wall. The
cotter reaches past the flood-hole rim on both sides = a clevis-pin pull-out stop
**wider than the bore**, so the pin is a **fixed pivot post** (≈0.1 mm axial play).
It is **geometric** — it cannot fracture like the old barb (a solid pin, nothing
flexes) nor slide like the old loose dowel (a positive cross member, not friction)
— and needs **no soldering iron**. The back-face recess **radially confines** the
cotter so it stays seated; **pull the cotter to service** the joint. (The back wall
is reachable because the mount is the bottom shaft-exit flange, not the back face.)
The **finger pins keep the heat-stake** cap (smaller, grip-loaded studs with no
clean external access — see below).

**Axial capture of each rotating element** (so an arm cannot slide along the pin):
every element is trapped between a back-boss **down thrust shoulder** and the pin's
**locating collar** above it (0.12 mm running gap each way). The crank/gear sits in
the low Z layer and lands on the plain back-boss; the **follower sits a layer higher**,
so its pivots (B_R, B_L) carry a **taller D-shaped boss** — full thrust shoulder on the
**outboard** half, cut away on the inboard half where the crank arm sweeps past the
follower pivot at full open. This trapped the old ~5.6 mm follower axial float down to
0.24 mm without fouling the crank.

### Finger pins — `melt_pin_finger_C` (C_R, C_L) + `melt_pin_finger_D` (D_R, D_L) (4 pins, 2 SKUs)

Plain stepped journal pins. From the top down: the **head seats on the finger
TOP**; a **fat neck** is the anti-wobble running bearing in the **fixed 2.6 mm
TPU finger bore**; a **slim land** journals the rigid arm or follower eye; and
the **melt-stud protrudes past the arm/follower-eye BOTTOM (exit) face**, where
the cap is melted. C reaches the crank layer (long `melt_pin_finger_C`); D
reaches the follower layer (short `melt_pin_finger_D`).

**Anti-wobble journal boss (2026-06 redesign):** each rigid C/D eye now grows a
**journal boss upward** to just under the finger, so the slim land runs
**continuously from the cap-recess floor up to the finger bottom** (L/D ≈ 3.6 at
C) instead of journaling a short eye then flag-poling across an empty gap — this
kills the finger's out-of-plane wobble. The **boss top is the under-finger thrust
shoulder**: the finger seats on it with a 0.12 mm running gap (head above + shoulder
below), so the old ~1 mm finger axial float collapses to a running fit and the finger
sits square on **both** bosses (they end at the same Z). The neck→land step floats
just above the shoulder, so there is no rotating thrust face to drag.

Because the cap face is **buried mid-cavity** once the mechanism is in the
housing, the finger pins are staked as a **bench sub-assembly**: build
{finger + crank arm + follower + the two C/D pins + 2 caps}, melt the 2 caps at
the arm/follower-eye bottoms while both pin ends are still reachable on the
bench, **then** drop that finished sub-assembly into the open-front housing.

**Assembly order is load-bearing:** the finger sub-assemblies must be staked on
the bench *before* they go into the housing, and the axle pins are capped from
outside the back wall *after* the mechanism is in. There is no tool-free pinch
release — a melted cap is permanent; to service a joint you slice the cap off
and melt on a fresh one.

---

## Assembly sequence

### Step 1 — Print prep and fit test

1. Confirm all parts are in the correct material: enclosure, cover, arms,
   followers, and `input_pinion_shaft` in **PA12-GF** (or PETG-HF for test);
   **all 8 pivot pins (`melt_pin_axle` ×4, `melt_pin_finger_C` ×2,
   `melt_pin_finger_D` ×2) and the 8 `melt_cap` retainers in PETG-HF**; fingers
   in **ether-based TPU ~95A**. Never PLA; never TPU for pins (see
   `UNDERWATER.md`). Have a **soldering iron** ready — it is the only tool the
   build needs (for melting the 8 caps).
2. **Deburr every pivot bore** — the 4 back-wall axle sockets / flood holes,
   the four C/D finger mount holes, the cover boss bores, and the two journal
   bores in the bottom wall — with a hand-spun countersink or deburring blade.
   Knock the first-layer elephant-foot lip off each bore mouth so pins enter
   square.
3. **Clean the gear flanks** on `drive_arm_R` and `drive_arm_L`: knock down
   layer ridges and seam witness on the teeth.
4. **Fit-test one melt pin + cap** against a scrap bore coupon (per
   `PRINTING.md` "Fit tuning"). Slip the pin through, slip a `melt_cap` over the
   protruding stud, and touch the soldering iron to the stud until it mushrooms
   the cap into a head **wider than the bore**. Confirm the formed head holds
   and the pin runs free in the bore. Tune the stud/cap fit before staking the
   real pins.
5. **Dry-snap the front cover once:** push it straight onto the bare enclosure
   until all **4 cantilever clips click** into their side-wall windows, then
   flex the four hooks outward and lift the cover off. Confirms clip geometry
   before you trap the mechanism.

---

### Step 2 — Bench-stake the two finger sub-assemblies

The finger pins are capped at the arm/follower-eye **bottom**, which is buried
mid-cavity once the mechanism is in the housing — so you cannot reach them
later. **Stake each finger as a bench sub-assembly first**, while both pin ends
are still reachable. Build **two** of these (one per side, a chiral pair).

For each side {`finger` + crank `drive_arm` + `follower`}:

1. Lay the crank arm and follower so the finger's two bracket eyes line up over
   the **C eye** (crank) and **D eye** (follower). The finger's ridged contact
   face must face **inboard** (toward the centreline) in the finished gripper —
   build the chiral pair accordingly (`finger_R` on the right arm/follower,
   `finger_L` on the left).
2. Drop a `melt_pin_finger_C` (the **LONG** pin) down through the finger eye at
   **C** and a `melt_pin_finger_D` (the **SHORT** pin) at **D**, head on the
   finger top. The fat neck runs in the fixed 2.6 mm TPU finger bore; the slim
   land journals the arm/follower eye; the melt-stud pokes past the eye
   **bottom**.
3. Slip a `melt_cap` over each protruding stud and **melt it with the soldering
   iron** into a head wider than the bore. Two caps per side, **4 caps total
   across both sub-assemblies**.
4. Check both pivots run free — the finger should pivot on each pin without
   wobble, and neither pin can pull out (the formed head holds).

You now have two finished {finger + arm + follower} sub-assemblies ready to
drop into the housing.

---

### Step 3 — Mesh and drop the two sub-assemblies into the housing

The enclosure prints **open-front**. The two drive arms must **interleave with
a half-tooth offset** so both jaws move symmetrically — get the timing right as
they go in.

1. Hold the two sub-assemblies at the **closed pose**: `drive_arm_L` crank
   points up and slightly inboard (~102° from +X); `drive_arm_R` is its mirror.
2. Bring the two sector gears together so their pitch circles touch on the
   centreline. **Before teeth engage, rotate one arm by half a tooth:**
   360° ÷ 16 ÷ 2 = **11.25°** — so a tooth of one gear drops into the valley of
   the other (teeth interleave, not tip-to-tip).
3. **Seat the right sub-assembly:** lower it so the `drive_arm_R` A_R bore and
   the `follower_R` B_R bore rest over their back-wall bosses. **Seat the left
   sub-assembly:** the `drive_arm_L` A_L bore and `follower_L` B_L bore over
   their bosses; the crown gear face on `drive_arm_L` must face the bottom (−Y)
   toward the input-pinion position. The arms are only located, not yet
   Z-captured (the axle pins do that in Step 4).
4. The cranks should now be a true mirror pair. **Check:** at closed, the
   C-pin base gap is ~9.86 mm. If jaws come out lopsided, the mesh is off by one
   tooth — lift out, re-offset 11.25°, re-seat.
5. Recheck both arms swing freely by hand and the gear mesh stays interleaved.

### Step 3a — Install the input drive shaft

1. **Push `input_pinion_shaft` UP into the journal from below:** the shaft is a
   plain cylinder (≤4.0 mm) below the pinion, so it feeds
   pinion-first up through the lower journal bore and the upper boss bore (one
   continuous 4.3 mm bearing). The pinion (Ø7.44 mm < the bore) passes through
   and enters the cavity, meshing the crown gear on `drive_arm_L` at the −Y
   azimuth. Push until the bottom shoulder lands on the flange.
2. **Confirm the +Y stop:** the bottom shoulder (OD 5.8 mm > bore) bottoms on the
   flange outer face — that is the push-in stop. (There is no mid-shaft collar;
   the older collar-in-pocket design was un-installable and was removed.) The
   shaft runs in flooded journal bores (no bushing) — confirm it turns freely.
3. The D-profile coupler end exits below the housing bottom, below the mounting
   flange. The shaft runs in flooded journal bores (no bushing needed); confirm
   it turns freely.
4. **Verify the crown/pinion mesh:** rotate the shaft slightly by hand. Both
   drive arms should move, confirming the crown/pinion stage is engaged. (Note:
   the crown/pinion faces were widened in the Phase-4 strengthening —
   `PINION_T 8 mm`, `CROWN_TOOTH_H 3 mm` — but the mesh and assembly are unchanged;
   `motor/DRIVETRAIN.md`.)
5. **Couple the actuator:** fit the printed adapter horn from the selected
   actuator (primary: DYNAMIXEL XW540-T260 smart serial servo; or the magnetic-
   coupling dry-pod for >30 m) onto the D-coupler. **Set the actuator's firmware
   current limit to the gear ceiling `T_safe`** before driving — the printed
   crown/pinion is the structural limit and the current limit is its protection.
   The same current telemetry is the gripper's grip-force sensor. See
   `motor/SELECTION.md`, `motor/SENSING.md`, `motor/ELECTRICAL.md`.

---

### Step 4 — Insert the 4 axle pins from the front

For each of **A_R**, **A_L**, **B_R**, **B_L**:

1. Orient the `melt_pin_axle` head-up (head toward the open front / cover side,
   melt-stud toward the back wall).
2. Drop it **straight down through the front-open cavity**, through the
   arm/follower bore and into the back-wall socket. The shank journals the eye
   and **bottoms on the back-bore step** (−Z stop); the **melt-stud threads the
   back-wall flood hole and pokes out past the exterior back face**.
3. The head sits just under where the cover boss will land; the arm/follower
   must **pivot freely** on the pin.

Repeat all four. **`pin_A_L`** is the axle pin for `drive_arm_L` — install it
the same way as `pin_A_R`. The left arm no longer has an integral shaft; it
rides on its axle pin like the right arm. After all four are in, the four
melt-studs protrude from the **outside of the back wall**.

---

### Step 5 — Flip the housing and melt the 4 back caps

> **The back wall must be accessible for this step.** It is *not* the mounting
> face — the mount is the bottom shaft-exit flange (Step 9) — so the back face
> is free. Keep it clear of any fixture while you stake the caps.

1. **Flip the housing** so the exterior back wall faces up and the four axle
   melt-studs point at you.
2. Slip a `melt_cap` over each stud and **touch the soldering iron to it** until
   it fuses into a **thermal-rivet head wider than the flood hole**. Four caps,
   one per stud. Each axle pin is now **riveted to the back wall = a fixed pivot
   post** — captured geometrically, not by the cover and not by friction.
3. Verify: tug each axle pin from the front — it must have essentially no axial
   slop and refuse to pull out. The arm/follower must still pivot freely on it.

This is the **fourth through eighth caps**: 4 finger caps were melted on the
bench (Step 2), 4 axle caps here — **8 caps melted in total**.

---

### Step 6 — Snap the front cover on

The axle pins are already captured by their melted back caps (Step 5), so the
cover is now purely a closure, not a pin retainer.

1. Align `front_cover` over the open front, the 4 hook clips facing the four
   side-wall windows (2 per long side).
2. **Push it straight on** until all **4 cantilever clips click** into their
   windows (the click is a little softer now that the tabs are slimmer, but the
   geometric hook capture — not the spring force — holds the cover). No tools,
   no fasteners.
3. Verify the cover sits flush and the mechanism still turns freely.

To remove later: flex all 4 hooks **outward** through the windows and lift the
cover straight off. The pins stay riveted in place — removing the cover does
not free them (slice a cap off only if you need to service that joint).

---

### Step 7 — Couple a waterproof actuator to the bottom D-shaft

1. Mate your **waterproof servo / actuator coupling** onto the **bottom
   D-profile coupler** on `input_pinion_shaft` (the D exits below the housing
   bottom flange — actuator couples from below). Coupler dimensions: radius
   5.0 mm, D-flat depth 1.4 mm, length 12 mm. The milled flat keys the
   coupling so it cannot slip.
2. Use an IP68/submersible servo, a potted hobby servo, or a sealed/oil-filled
   actuator with a pressure compensator for deeper work. See `UNDERWATER.md`
   §6. The actuator carries the **only** waterproofing burden in the system —
   the gripper itself is passive and fully flooded.

---

### Step 8 — Mount via the bottom flange

1. The **bottom flange** carries **4 × M4 clearance holes** positioned around
   the shaft exit. Attach the gripper to your robot arm or mount with M4 bolts
   through these holes. The actuator couples below the flange to the D-shaft.
   (This bottom flange is the mounting face — which is why the back wall stayed
   free for the axle-cap melt in Step 5.)
2. **Galvanic isolation:** if your robot arm is metal, use **nylon or PTFE
   shoulder bushings + isolating washers** on every flange bolt so no
   metal-to-metal contact path exists between the gripper body and the arm
   (see `UNDERWATER.md` §5). The gripper itself contributes no metal — the
   isolation lives at this interface.

---

## Function test (in air)

1. Rotate the input shaft — turn the actuator or the bottom D-coupler directly.
2. **Both jaws must open and close symmetrically**, splaying ~18° outward as
   they open (funnel mouth) and coming nearly together at closed.
3. Check the mesh: smooth, low-backlash engagement through the full travel,
   no tight spots or skipped teeth. If one jaw leads the other, the gears are
   off by one tooth — return to Step 3 and re-time with the 11.25° half-tooth
   offset.
4. Confirm all pivots move freely. Press a finger's contact face and confirm
   the Fin Ray tip curls toward/around the load.

---

## Flood check (before it gets wet)

The gripper is designed to **flood completely** — there are no sealed air
pockets inside. Trapped air would add buoyancy and create pressure differential
on the walls, so verifying full flooding matters.

1. **Drain/flood holes clear:** confirm the 8 bottom-face drain holes, the 4 low
   side-wall holes, the 4 snap-clip windows, and the 3 front-cover vent holes
   are all open and unobstructed (not bridged shut by print artefacts).
2. **Cover vent holes:** the front cover carries **3 × Ø1.8 mm vent holes**
   in a symmetric row at (−34 / 0 / +34, +12) mm, positioned over the open cavity
   toward the finger side. These let trapped air escape when the gripper is
   oriented front-up. Confirm all three holes are clear through the cover plate.
3. **Submerge and watch bubbles:** lower the gripper **mouth-down** first,
   then **mouth-up** — bubbles must escape both ways and the cavity must fully
   flood. Cycle the jaws open↔closed underwater to flush any last trapped air.
4. Once it floods and drains freely in any orientation with no retained air
   bubble, the flooded build is ready for use.

After every salt dive: **rinse with fresh water**, cycle the jaws to flush
grit, dry, and inspect.

---

## Disassembly (the melt caps are permanent)

A heat-staked cap is a formed rivet head — there is no pinch release. To open a
joint you **slice its `melt_cap` off** (flush cutter or knife at the cap root),
then melt a **fresh** cap on at reassembly. Caps are cheap to reprint; the pins
themselves are reusable. Reverse in order:

1. **Front cover:** flex all **4 cantilever hooks outward** through the
   side-wall windows simultaneously and lift the cover straight off. (The pins
   are *not* held by the cover, so this alone frees nothing.)
2. **Axle pins (A_R, A_L, B_R, B_L ×4):** slice the **4 back caps** off the
   melt-studs at the exterior back wall, then lift each pin straight up out of
   the front-open cavity.
3. **Input drive:** with the actuator detached, pull the `input_pinion_shaft`
   straight DOWN and out the bottom of the journal (the bottom shoulder won't
   pass the bore upward, so it leaves the way it went in — downward).
4. **Arms and finger sub-assemblies:** lift the two {finger + arm + follower}
   sub-assemblies out of the cavity. All four arms ride on axle pins; none have
   integral shafts.
5. **Finger pins (C/D ×4), only if servicing a finger:** slice the cap off the
   arm/follower-eye bottom of each finger pin and push the pin out to separate
   the finger from its arm/follower. Otherwise leave each finger sub-assembly
   intact and reuse it whole.

Each pin is reusable; every cap is single-use (slice off, reprint, re-melt).

---

## Print → assemble quick-start

1. **Print:** `plate_rigid_1.stl` (PETG/ASA, 0.12–0.20 mm, no supports) and
   `plate_tpu_1.stl` (TPU 95A, 0.15–0.20 mm, slow, no supports). See
   `PRINTING.md` and `PRINT_PLATES.md` for full settings.
2. **Post-process:** deburr all pivot bores; clean gear flanks; test-flex each
   cover clip. Have a **soldering iron** ready for the 8 melt caps.
3. **Fit-test one melt pin + cap** on a scrap bore coupon; melt the cap and
   confirm the formed head clears the bore and holds before staking the real
   pins.
4. **Assemble in order:** bench-stake the 2 finger sub-assemblies (finger + arm
   + follower + 2 pins, melt 2 caps each) → mesh + drop both sub-assemblies into
   the housing → push `input_pinion_shaft` UP into the journal from below
   (pinion-first) → insert the 4 axle pins from the front → flip and melt a cap
   onto each of the 4 back studs → snap on the front cover → bolt on the
   actuator. (8 caps melted in total.)
5. **Function check:** rotate the bottom D-shaft; both jaws must open/close symmetrically.
6. **Flood check:** submerge, watch bubbles clear, cycle jaws wet.
7. **Read `UNDERWATER.md`** for material prep and seawater guidance before the
   first dive.

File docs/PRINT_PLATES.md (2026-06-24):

# Print plates — drop-into-slicer layout

Generated by `make_print_plates.py` from `parts/*.stl` (which come from
`export_parts.py` → `gripper.gen_step()`, CLOSED pose). Each part is rotated to
its **supportless** print orientation, seated on Z=0, then shelf-packed onto
build plates for a common bed.

> **REGENERATE AFTER ANY GEOMETRY CHANGE.** These plates are a *derived*
> artifact. When `gripper.py` geometry changes (e.g. the pin / heat-stake-cap
> geometry is retuned), the integrator MUST re-run **both** steps:
> ```bash
> source /home/andre/.cad-venv/bin/activate
> python export_parts.py        # refresh parts/*.stl
> python make_print_plates.py   # refresh print_plates/
> ```
> Stale plates do not reflect the current design. `make_print_plates.py` wipes
> and rebuilds `print_plates/` on every run, so it is safe to re-run.

## What the script writes

- `print_plates/oriented/<part>.stl` — every unique part, **already rotated** to
  its print orientation with min-Z on the bed. Drop a single one in if you only
  need that part.
- `print_plates/plate_rigid_1.stl` — the **PA12-GF** structural parts (body, cover,
  arms, followers, input pinion shaft), packed.
- `print_plates/plate_petg_1.stl` — the **PETG-HF** pins and caps on their own
  plate: all 8 journal pins (`melt_pin_axle` ×4, `melt_pin_finger_C` ×2,
  `melt_pin_finger_D` ×2) + 8 `melt_cap` retaining caps. These print in PETG-HF
  because PETG-HF heat-stakes cleanly under a soldering iron; glass-filled PA12-GF
  does not.
- `print_plates/plate_tpu_1.stl` — the two **TPU** Fin Ray fingers, packed
  **separately** because they print in a different material.

Plates are split by MATERIAL by design (PA12-GF / PETG-HF / TPU) — you swap
filament between the three plates.

## Bed & packing

- Default bed: **256 × 256 mm** (configurable: `--bed X Y`).
- Spacing between parts: **5 mm** (`--spacing`).
- Packing: shelf pack, widest-first, left→right, wrap to a new shelf, then a new
  plate if it overflows. Simple and deterministic.

Re-run for a smaller printer, e.g. a 220 mm Ender bed:
```bash
python make_print_plates.py --bed 220 220
```
At 220×220 everything still lands on the same 3 plates (rigid footprint is only
~236×108 — it re-packs onto a couple more shelves but fits).

## Plate layout (256 × 256 mm, 5 mm spacing)

### `plate_rigid_1.stl` — PA12-GF — **7 parts**, footprint ≈ 236 × 108 × 33 mm

| Part | Qty | Oriented bbox (mm) | Orientation |
|---|---|---|---|
| `enclosure` | 1 | 96.0 × 41.0 × 30.0 | open slot/cavity face **+Z up**, drain-floor on bed (as-exported); slimmer 4 mm back wall |
| `front_cover` | 1 | 102.4 × 36.0 × 23.5 | **flip 180° about X**: flat outer face on bed (1.2 mm perimeter chamfer = small first-layer bevel), the 4 slim (2.0 mm) snap clips point up — their chamfered free tips are at the print-top, so they self-support too |
| `drive_arm_L` | 1 | 26.5 × 51.2 × 8.0 | flat plate face-down (as-exported); crown gear on +Z face; no integral shaft |
| `drive_arm_R` | 1 | 26.6 × 51.2 × 5.0 | flat plate face-down (as-exported) |
| `follower` | **2** | 11.2 × 40.0 × 5.0 | flat bar face-down (as-exported) |
| `input_pinion_shaft` | 1 | 11.6 × 11.6 × 33.0 | **rotate 90° about X**: shaft-axis vertical, D-coupler/shoulder end on bed, pinion teeth at top |

### `plate_petg_1.stl` — PETG-HF — **16 parts** (8 pins + 8 caps), footprint ≈ 60 × 30 × 27 mm

| Part | Qty | Oriented bbox (mm) | Orientation |
|---|---|---|---|
| `melt_pin_axle` | **4** | 7.8 × 7.8 × 20.8 | **flip 180° about X**: head down on bed, melt-stud up; plain stepped cylinder, self-supporting |
| `melt_pin_finger_C` | **2** | 7.8 × 7.8 × ~29 | **flip 180° about X**: LONG crank-layer pin; head down on bed, melt-stud up |
| `melt_pin_finger_D` | **2** | 7.8 × 7.8 × ~24 | **flip 180° about X**: SHORT follower-layer pin; head down on bed, melt-stud up |
| `melt_cap` | **8** | ~6 × 6 × ~3 | tiny retaining cap; disc face on bed, bore up; no supports |

### `plate_tpu_1.stl` — TPU 95A — **2 parts**, footprint ≈ 68 × 101 × 10 mm

| Part | Qty | Oriented bbox (mm) | Orientation |
|---|---|---|---|
| `finger_R` | 1 | 28.0 × 96.2 × 10.0 | flat on a 28×96 Z-face, build height 10 mm (as-exported) |
| `finger_L` | 1 | 28.0 × 96.2 × 10.0 | flat on a 28×96 Z-face, build height 10 mm (as-exported) |

## Part quantities (full assembly = 25 printed parts)

| Part | Qty | Why |
|---|---|---|
| enclosure | 1 | one housing |
| front_cover | 1 | one snap-on cover |
| drive_arm_L | 1 | left arm (crown gear on +Z face); rides on `melt_pin_axle` |
| drive_arm_R | 1 | right arm; rides on `melt_pin_axle` |
| follower | 2 | one per side (L/R link bars are congruent → same file) |
| melt_pin_axle | **4** | the 4 internal axle pivots (`pin_A_R`, `pin_A_L`, `pin_B_R`, `pin_B_L`) |
| melt_pin_finger_C | **2** | the 2 LONG crank-layer finger-pivot pins (`pin_C_R`, `pin_C_L`) |
| melt_pin_finger_D | **2** | the 2 SHORT follower-layer finger-pivot pins (`pin_D_R`, `pin_D_L`) |
| melt_cap | **8** | one heat-staked retaining cap per pivot pin (8 pins → 8 caps) |
| finger_R | 1 | right Fin Ray finger (chiral) |
| finger_L | 1 | left Fin Ray finger (chiral mirror) |
| input_pinion_shaft | 1 | pinion + vertical shaft + capture collar + D-coupler (new right-angle drive) |
| **Total** | **25** | **3 plates** (1 rigid PA12-GF + 1 PETG-HF + 1 TPU) |

`pin_A_L` is now a separate axle pin (`melt_pin_axle`, same geometry as `pin_A_R`)
— the left arm no longer carries an integral horizontal shaft. The right-angle
drive input shaft is `input_pinion_shaft`, a separate printed part. Zero bought
hardware — every pin is a printed PETG-HF journal retained by a heat-staked
`melt_cap` (slip the cap over the pin's melt-stud, fuse it with a soldering iron).

## Totals & estimates

- **Plates: 3** (1 rigid PA12-GF, 1 PETG-HF, 1 TPU).
- **Solid material volume: ≈ 103.1 cm³** (geometric solid volume, summed over all
  25 parts, BEFORE walls/infill — the 8 tiny caps add little; actual filament will
  be lower for the low-infill housing and higher only if you go 100 % on small
  parts).
- **Print-time estimate: not produced — no slicer CLI was found on PATH.** The
  script auto-detects `prusa-slicer`, `orca-slicer`, `superslicer`, `slic3r`,
  `CuraEngine`; install one and re-run `make_print_plates.py` to get per-plate
  time + filament grams (it slices each plate at `--layer`, default 0.2 mm).

## Overhang / support summary (chosen orientations)

Down-facing surface steeper than 45° from horizontal, per part, in the oriented
pose (mm² needing support, excluding the first layer):

| Part | Support area | Verdict |
|---|---|---|
| drive_arm_R, follower, melt_pin_axle, melt_pin_finger_C/D, melt_cap | 0 mm² | fully supportless (plain stepped cylinders / tiny discs — no barb bridge) |
| finger_R / finger_L | ~1 mm² (first-layer noise) | supportless |
| front_cover | 184 mm² | supportless (clip hook underlips bridge) |
| drive_arm_L | 21 mm² | as-exported, flat plate on bed; crown gear on +Z face prints as concentric rings — supportless |
| input_pinion_shaft | 89 mm² | shaft-axis vertical (90° X rot); collar mid-shaft is a ~1.8 mm radial bridge — supportless |
| enclosure | 1259 mm² | mostly bridges (interior floor ceilings); the **back flange** is the one feature that may want a few support pillars / a skirt |

See `PRINTING.md` → "Supportless orientation table" for the full per-part print
recipe, and the CONSTRAINTS block at the end of this audit for the pin / heat-stake
geometry that must be preserved.

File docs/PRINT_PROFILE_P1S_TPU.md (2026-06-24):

# Gripper fingers — Bambu TPU 95A HF on a Bambu Lab P1S (0.4 mm hardened nozzle)

Complete, importable print stack for the two Fin Ray fingers, with **every setting
specified and justified**, plus the FEA re-check confirming all the stats hold for
**Bambu TPU 95A HF** specifically. Target machine: **Bambu Lab P1S, 0.4 mm hardened
steel nozzle**, slicer **Bambu Studio**.

> The fingers are the only TPU parts. The rigid structural parts (PA12-GF) and the
> heat-stake pivot pins + retaining caps (all PETG-HF) print on the same P1S with
> stock Bambu system profiles — see §6.

> **Why Bambu TPU 95A HF (vs the old eSUN eTPU-95A):** the "HF" (high-flow) grade
> prints at ~3× the throughput of standard TPU 95A (max volumetric speed ~12 mm³/s,
> up to ~200 mm/s) and — decisively for this repo — Bambu **publishes ISO 527
> printed-specimen mechanical data**, so the finger FEA now runs on a *measured*
> modulus and strength instead of the old 40 MPa guess. See §5.

## TL;DR

1. Import the two profiles in `profiles/` (Bambu Studio → **File → Import → Import
   Configs…**): the **filament** profile `Bambu_TPU-95A-HF_@P1S_0.4.json` and the
   **process** profile `finger_TPU_0.16mm_@P1S_0.4.json`. (Or start from Bambu Studio's
   own system **Bambu TPU 95A HF** preset and apply the process profile.)
2. **Dry first: 70 °C for 8 h** (Bambu spec). Run it from an **external spool, NOT the
   AMS** — Bambu's own system profile states 95A HF is *"too soft and not compatible
   with the AMS."* Keep it in a dry box while printing.
3. **Use the Textured PEI plate, NO glue** (see §1 — glue *over*-adheres TPU on
   textured PEI; glue is only for smooth plates). Select the imported filament +
   process, slice `print_plates/plate_tpu_1.stl` (both fingers), print.

The FEA (`fea/UNIVERSAL_FINGER.md`, `fea/SCALABILITY.md`) is **confirmed valid for
Bambu TPU 95A HF**: see §5 — the force-targeted safety margins stay **~8×** (and edge
slightly up on the measured 27.3 MPa strength), and the design ranking is unchanged.

---

## 1. Hardware & material prep (do these or the print fails)

| Item | Setting | Why |
|---|---|---|
| Spool path | **External spool — NOT the AMS** | Bambu's own `Bambu TPU 95A HF @base` profile states: *"This filament is too soft and not compatible with the AMS."* Feed it straight to the toolhead from an external spool; the soft 95A buckles in the AMS feed + long PTFE. |
| Drying | **70 °C ≥ 8 h** (Bambu spec; or X1-bed 80–90 °C 12 h), keep in a dry box while printing; storage <20 % RH | TPU 95A HF is "highly sensitive to humidity"; wet TPU = stringing, bubbles, weak layers. |
| Nozzle | **0.4 mm hardened steel** (you have this) | Fine for TPU. Use a clean/new or cold-pulled nozzle — TPU drags old residue. Do **not** use a 0.2 mm nozzle for TPU. |
| Extruder | P1S stock direct extruder | HF flows easily; the P1S direct extruder handles it, fed straight from the external spool. |
| Plate | **Textured PEI plate, NO glue** (preferred) | Bambu Wiki TPU guidance: the textured PEI keys TPU mechanically — "excellent adhesion without adhesives," and *"applying glue may cause excessive adhesion."* Keep the bed at **30–35 °C** (low) so the large flat 28×96 finger footprint stays removable; release by cooling, lifting a corner, squirting **IPA** into the gap, then peeling slowly (don't pry a hot part — chips the PEI). **Alternative:** a smooth plate (Cool/Engineering/High-Temp) needs **glue** there as a release barrier — the datasheet's blanket "Bed prep: Glue" line is for those smooth plates, not the textured one. The Engineering plate gives a glossy bottom you don't need on a finger base, so textured-PEI/no-glue is the pick. |
| Orientation | **Flat on the 28×96 face** (as in `print_plates/`) | Fin Ray cells lie in the build plane → self-supporting, no supports; in-plane bending (the grip mechanism) runs in the **strong X-Y direction** (E 9.8 MPa / 27.3 MPa vs the weaker through-Z 7.4 / 22.3). |

---

## 2. The two importable profiles

| File | Type | Inherits (real system preset) | Shows up for |
|---|---|---|---|
| `profiles/Bambu_TPU-95A-HF_@P1S_0.4.json` | filament | **`Bambu TPU 95A HF @BBL P1S`** | **Bambu Lab P1S 0.4 nozzle** |
| `profiles/finger_TPU_0.16mm_@P1S_0.4.json` | process | `0.20mm Standard @BBL X1C` | Bambu Lab P1S / P1P / X1C, 0.4 nozzle |

Both are `"from": "User"`, `instantiation: "true"`, and inherit a real Bambu system
preset so every value not overridden resolves to Bambu's tested defaults.

- **Filament** inherits Bambu's own **`Bambu TPU 95A HF @BBL P1S`** (verified against
  the BambuStudio profile repo). You own the filament, so your Studio already ships
  that preset — the import resolves cleanly and you get Bambu's tested nozzle/flow/
  retraction and the *Direct Drive High Flow* template for free. This preset overrides
  **only** the gripper-specific notes + start g-code (external-spool / textured-PEI /
  drying reminders) and locks `compatible_printers` to P1S 0.4. **Nothing material is
  re-typed**, so there's nothing to drift from Bambu's calibration.
- **Process** inherits `0.20mm Standard @BBL X1C` (the P1S has no dedicated `@BBL P1S`
  process; it uses the X1C process via `upward_compatible_machine`, confirmed present
  in your Studio's process dropdown).

**Import:** Bambu Studio → File → Import → *Import Configs…* → pick both `.json`. They
appear under **User Presets** in the filament and process dropdowns when a P1S 0.4 is
selected.

> **Version must match your installed profiles.** Bambu Studio silently drops configs
> whose `version` is incompatible with the loaded BBL vendor profile ("There are 0
> configs imported. Only non-system and compatible configs"). These files are set to
> **`"version": "2.6.0.5"`** to match BBL profile **02.06.00.05** (Bambu Studio 2.6).
> If your Studio is a different release, set both files' `version` to your installed
> BBL major.minor (Help → About → version, or check `BambuStudio.conf`). The files use
> the exact user-preset shape Studio writes (`from: User`, `inherits`, `*_settings_id`,
> extruder-variant arrays — no `type`/`instantiation`/`setting_id`).

If the filament import ever warns the *parent* preset is missing, your Studio's
TPU-95A-HF system preset name differs — re-point `"inherits"` to the exact name in your
filament dropdown (or duplicate Bambu's preset in Studio and paste the two
`filament_notes`/start-g-code reminders in).

---

## 3. Filament settings — what you inherit + what we override

This preset **inherits `Bambu TPU 95A HF @BBL P1S`** (Bambu's own tested values, verified
against the BambuStudio profile repo) and then applies a small **anti-stringing / wall-streak
tune** on top — added after a first print came out very stringy with streaks along the walls
on *dried* filament, i.e. a genuine profile issue, not moisture (see §3a). The inherited base
values are:

| Setting | Inherited value (Bambu system) | Note |
|---|---|---|
| `nozzle_temperature` / initial layer | **230 °C / 230 °C** | Bambu's tested temp for 95A HF (same for both — no hotter first layer). |
| `filament_flow_ratio` | **1.0** | Bambu's calibrated flow for HF on the P1S. (Don't drop it to "under-extrude for thin walls" without a flow-calibration print — Bambu tuned 1.0.) |
| `filament_max_volumetric_speed` | **12 mm³/s** | The HF headline — ~4× the old eSUN cap (3.0). The finger's slowest member draws ~1.3 mm³/s, so it's a generous ceiling; it's what lets the §4 process speeds rise. |
| `filament_retraction_length` / speed / deretraction | **0.8 mm / 10 mm/s / 10 mm/s** | Bambu's values; minimal, slow retract so soft filament isn't pulled into the heatbreak. |
| `filament_density` | **1.22 g/cm³** | ISO 1183 (weight/cost only). |
| HF flow template, pressure advance, fan curve | inherited | comes with the `Direct Drive High Flow` template the system preset includes. |

Overrides — the **anti-stringing tune** (mechanical) plus the operator reminders:

| Override | Was (inherited) | Now | Why |
|---|---|---|---|
| `nozzle_temperature` | 230 °C | **220 °C** | Less melt ooze → less stringing. (Initial layer kept **230 °C** for bed adhesion.) |
| `filament_retraction_length` | 0.8 mm | **1.0 mm** | A touch more pull-back; modest so soft TPU isn't dragged into the heatbreak. |
| `filament_retraction_speed` / deretraction | 10 / 10 mm/s | **30 / 25 mm/s** | The big one — the stock 10 mm/s is far too slow, so ooze leaks out during the retract. Retract fast. |
| `filament_z_hop` / type | 0 (OFF) | **0.4 mm / Auto Lift** | **Fixes "streaks along the walls"** — lifts the nozzle clear of printed walls on travel so it stops smearing across them. |
| `filament_wipe` | off | **on** | Wipes the nozzle as it retracts → less ooze blob to start a string. |
| `filament_retract_when_changing_layer` | off | **on** | Retract at the Z-seam → cleaner seam, less seam stringing. |
| `filament_retraction_minimum_travel` | — | **1 mm** | Don't retract for sub-1 mm hops (avoids over-retraction grinding the soft TPU). |
| `name` / `compatible_printers` / start-gcode / notes | — | gripper preset · **P1S 0.4 only** · external-spool-not-AMS · textured-PEI-no-glue · dry 70 °C 8 h | operator reminders carried with the profile. |

`filament_flow_ratio` (1.0), `filament_max_volumetric_speed` (12), pressure advance and the
fan curve are **left at Bambu's calibration** — the fix is retraction/temperature/travel, not flow.

### 3a. If it's *still* stringy after this

Apply in order (one at a time, re-print a small test):
1. **Re-dry the spool** — TPU re-absorbs moisture fast; "dried a while ago" ≈ wet. 70 °C, 8 h, print from a dry box. (You said it was dried recently, so this tune targets the profile first — but moisture is still the #1 cause if streaks have a fuzzy/popped texture.)
2. **Nozzle 220 → 215 °C** (watch layer adhesion — the finger flexes; don't go below ~210).
3. **Slow the outer wall** 30 → 22 mm/s (process profile `outer_wall_speed`) — slower walls ooze less and look cleaner.
4. **Retraction 1.0 → 1.2 mm** (not higher on direct-drive TPU — risks grinding).
5. Check for a **partially clogged / TPU-residue nozzle** (cold-pull) — TPU drags old material and prints rough.

> **Cooling note (not overridden — read before a fatigue-critical build):** the finger
> flexes in service, and high part-cooling can weaken the interlayer (Z) bonds (the
> weak 7.4 MPa / 22.3 MPa direction). This preset leaves fan at Bambu's TPU default;
> if you want to protect Z-bonds you can lower max fan to ~50–80 % — **untested under
> cycling**, so treat Bambu's default as the validated setting unless you fatigue-test.

---

## 4. Process (print) settings — every value + why (`Gripper finger TPU 0.16mm`)

The shipped finger has **thin graded walls** (contact 1.2 / rib 1.6 / spine 1.8 mm)
and **0.6 mm grip teeth** at 2.2 mm pitch — the process is tuned to print every wall
**fully solid** (the FEA's 100 %-dense-wall basis) and resolve the teeth/ribs.

> **HF speed-up:** because TPU 95A HF allows ~12 mm³/s, the wall/infill speeds below
> are raised vs the old eSUN profile (outer 20→30, inner 30→60, infill 40→90,
> solid 35→70 mm/s). The 12 mm³/s volumetric cap in the filament profile still governs
> the true ceiling on any thick move, so quality on the fine ribs/teeth is preserved
> while bulk infill runs much faster. First-layer and outer-wall stay slow for a clean
> grip face.

| Setting | Value | Rationale |
|---|---|---|
| `layer_height` | **0.16 mm** | Resolves the 2.2 mm-pitch grip teeth and thin ribs cleanly; finer Z also bonds better. |
| `initial_layer_print_height` | 0.20 mm | Robust first layer. |
| `wall_loops` | **5** | Enough loops that every member fills with perimeters (the slicer uses only as many as fit). |
| `line_width` / `outer_wall` / `inner_wall` | **0.40 mm** (all walls) | **Critical:** at 0.40 mm the **1.2 mm contact beam = exactly 3 flush perimeters (0.40×3) — no gap-fill**. The contact beam is the most cyclically-loaded member, and gap-fill on TPU is where layer bonding gets unreliable; flush perimeters avoid it. Ribs 1.6 mm = 4 flush; spine 1.8 mm = 4 + a small 0.2 mm gap-fill (interior, non-critical). |
| `wall_generator` | **classic** | Predictable perimeters on thin TPU walls (Arachne adds variable-width gap-fill on near-integer walls). |
| `detect_thin_wall` | 1 | Captures the 1.2 mm contact beam as solid wall. |
| `initial_layer_line_width` / `sparse_infill_line_width` | 0.50 / 0.45 | Wider first layer for adhesion; wider infill is fine (interior). |
| `top/bottom_shell_layers` | **4 / 4** | Dense skins on the base floor/cap. |
| `sparse_infill_density` | **100 %** | Matches the FEA assumption (fully-dense walls) and keeps the solid base/bracket and grip-ridge insets dense. The finger is small (~30 g), so 100 % is cheap. |
| `sparse_infill_pattern` | **`zig-zag`** | Bambu's serialized value for the UI's "Rectilinear" pattern (plain `"rectilinear"` is **not** a valid enum value — Studio silently falls back to `cubic`, which then conflicts with 100 % density). `zig-zag` supports 100 %. Moot at 100 % anyway (solid), but must be a 100 %-capable pattern to avoid the import-time "Cubic doesn't support 100 %" dialog. |
| `outer_wall_speed` | **30 mm/s** | Slow walls = clean grip face. Raised modestly from 20 (HF tolerates it) but kept slow for surface quality. |
| `inner_wall_speed` | 60 mm/s | HF throughput. |
| `sparse_infill_speed` | 90 mm/s | HF — bulk interior; volumetric cap (12) governs. |
| `internal_solid_infill_speed` | 70 mm/s | — |
| `top_surface_speed` | 30 mm/s | Clean top skins. |
| `gap_infill_speed` | 40 mm/s | — |
| `initial_layer_speed` | **18 mm/s** | Slow, sure first layer. |
| `travel_speed` | 200 mm/s | Travel can be fast (no extrusion). |
| `default_acceleration` | **3000 mm/s²** | **Reduced from the P1S stock 10000.** Soft TPU lags under high accel → blobs/ringing; lower accel = consistent extrusion. |
| `outer_wall_acceleration` | 1500 mm/s² | Gentle on the visible/grip walls. |
| `initial_layer_acceleration` | 500 mm/s² | Calm first layer. |
| `seam_position` | **back** | Keeps the layer seam **off the grip-ridge contact face** (the object side). |
| `brim_type` / `brim_width` | outer_only / **5 mm** | TPU + narrow footprint needs a brim to not peel. |
| `brim_object_gap` | 0.10 mm | Easy brim removal from the flexible part. |
| `elefant_foot_compensation` | 0.15 mm | With the part's base chamfer, keeps the first layer true. |
| `enable_support` | **0 (off)** | Flat orientation is self-supporting. |
| `ironing_type` | no ironing | Would smear the grip teeth. |
| `wall_sequence` | inner → outer | Better outer-wall surface on the grip face. |
| `compatible_printers` | P1S / P1P / X1C 0.4 | P1S visibility. |

---

## 5. FEA re-check for Bambu TPU 95A HF (the stats hold — now on MEASURED data)

**Bambu TPU 95A HF TDS (V1.0)** — ISO 527 / ISO 178 / ISO 1183, **printed specimens**
(this is the upgrade: eSUN never published a modulus, so the repo used a 40 MPa guess):

| property | Bambu value | used in FEA | note |
|---|---|---|---|
| Young's modulus | **9.8 MPa (X-Y) / 7.4 MPa (Z)** (ISO 527, anisotropic) | E **9.8 MPa** in-plane (grip); **7.4 MPa** through-Z (underwater crush) | The finger prints flat, so in-plane bending uses 9.8. Caveat: this is the ISO 527 **initial-tangent** modulus; a Fin-Ray at finite wrap strain is hyperelastic, so absolute forces are order-of-magnitude. Part of the change from the old 40 MPa "secant guess" is therefore *definitional*, not the material being weaker. |
| Tensile strength | **27.3 MPa (X-Y) / 22.3 MPa (Z)** (ISO 527) | strength **27.3 MPa** in-plane; **22.3 MPa** through-Z | Measured printed-specimen values replace the old shaky "25 MPa" estimate. For a 95A elastomer at >650 % elongation this is a stress-ceiling proxy, not a brittle yield. |
| Poisson ratio | (not published) | ν **0.42** | typical TPU 0.42–0.48. **ν relaxed from a TPU-realistic ~0.48 to 0.42 to partially mitigate linear-tet volumetric locking** — not a cure; see `fea/FEA.md` locking-diagnostic ν-sweep. |
| Density | 1.22 g/cm³ | — | (was 1.21 for eSUN — buoyancy change negligible). |
| Elongation at break | >650 % (X-Y) / >480 % (Z) | — | hugely ductile; failure is fatigue/tear, not brittle yield. |
| Water absorption | 1.08 % saturated (25 °C/55 % RH) | — | low uptake; soak-test still advised for sustained immersion (chemistry not stated). |
| Hardness | 95 A | — | — |

**Modulus sensitivity** — the baseline finger sensitivity bracket is re-centered on the
measured 9.8 MPa: **E = 7 / 9.8 / 12 MPa** (force-targeted to a 12 N grasp, strength
27.3 MPa). Because internal stress at a *fixed force* is set by the load, not the
stiffness (St-Venant), the von-Mises margins are **essentially modulus-independent
(~8× across the bracket)** — exactly as the old 30/40/60 bracket showed; only the
absolute number-line shifted. The measured strength rising 25→27.3 MPa nudges the
margin slightly **up**.

**Two reporting frames (both honest, don't conflate them):**
- **Force-targeted** (`REPORT_MODE="grip"`, the basis for the published per-shape
  margins and the universal ranking): margins and ranking are **modulus-insensitive →
  UNCHANGED** by the eSUN→Bambu switch. The (~0.65) universal score and the
  scalability band (0.6–1.1×) **stand as published**.
- **Closure-targeted** (`REPORT_MODE="closure"` at 8 mm, the production code default
  used for the wrap renders): grip force and stress scale ~linearly with E, so at the
  measured E = 9.8 MPa the absolute grip-at-8 mm baseline is **~2.3 N / peak vM
  ~0.81 MPa** (down ~4× from the old 40 MPa figure of 9.3 N / 3.30 MPa) — but this is
  an actuator-travel/absolute-force detail, and the repo's posture is rank/size, not
  certified absolute newtons. Margin at this closure is still ~34× vs 27.3 MPa.

Re-run yourself: `eval_finger.py <name> production '{"_E":9.8,"_strength":27.3}' screen`
(the harness accepts `_E` and `_strength` overrides), or sweep E with
`GRIPPER_E_TPU=7 python iter_harness.py …`.

---

## 6. The other gripper parts on the P1S (not TPU)

The fingers are the only TPU parts. For completeness on the same P1S + 0.4 hardened
nozzle:

- **Heat-stake pivot pins + caps (`melt_pin_*` ×8 + `melt_cap` ×8) — all PETG-HF.**
  Both finger-pin SKUs (`melt_pin_finger_C`/`_D`), the `melt_pin_axle` pins (PETG-HF,
  not PA12-GF — glass-filled nylon melts poorly under a soldering iron) and the 8
  `melt_cap` retainers print in the same PETG-HF. Use Bambu's stock **Bambu PETG-HF
  @BBL P1S** filament + a 0.16–0.20 mm process; 100 % infill, 5–6 walls (they're small
  locking parts). Prints cleanly on the P1S.
- **Rigid parts (enclosure, arms, followers, cover, shaft) — spec'd PA12-GF.**
  PA12-GF is marginal on a P1S: it needs ~260–290 °C (within the P1S's hardened-hotend
  range) **but the P1S has no actively heated chamber**, so glass-filled nylon is
  warp-prone on larger parts. Realistic P1S-friendly substitutions that keep the
  rigidity: **Bambu PAHT-CF** or **PETG-CF** (both have stock P1S 0.4 profiles and want
  the hardened nozzle you have), or plain **PETG-HF** for a lower-spec build. Keep the
  enclosure closed and use a brim.

---

## Sources

- **Bambu TPU 95A HF Technical Data Sheet V1.0** — Bambu Lab (ISO 527 Young's modulus
  9.8/7.4 MPa, tensile 27.3/22.3 MPa, elongation >650 %/>480 %, density 1.22 g/cm³,
  water absorption 1.08 %, melting 183 °C; nozzle 220–240 °C, bed 30–35 °C (glue for
  smooth plates; textured PEI no-glue per the Bambu Wiki TPU guide),
  dry 70 °C 8 h, max vol speed ~12 mm³/s, <200 mm/s, fan on, retraction 0.8–1.4 mm).
- Bambu Studio profile schema — `github.com/bambulab/BambuStudio`
  `resources/profiles/BBL/{filament,process,machine}` (Generic TPU + 0.20mm Standard
  @BBL X1C + P1S machine profile; key names, `compatible_printers`, inheritance).
- FEA: `fea/UNIVERSAL_FINGER.md`, `fea/SCALABILITY.md`, `fea/scripts/eval_finger.py`.

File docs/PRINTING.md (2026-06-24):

# 3D-printing guide

How to print the geared four-bar / Fin Ray gripper (`gripper.py`, `README.md`).
This gripper is **fully 3D-printed with ZERO bought hardware** — no screws, no
bolts, no metal dowels. Every pivot is a plain printed journal pin retained by a
heat-staked (melt-riveted) cap, and the front cover clicks on with integral
cantilever clips. The one tool the build needs is a **soldering iron** to melt the
8 caps. This guide covers material profiles, per-part settings, supportless
orientations, and the fit-tuning workflow.

Companion documents:
- `UNDERWATER.md` — material chemistry and seawater prep.
- `ASSEMBLY.md` — assembly order and snap-fit insertion.
- `PRINT_PLATES.md` — plate layout, regeneration commands, bbox table.
- `MATERIALS.md` — when it exists: full material comparison, creep/UV/salt
  performance data. PETG-HF test prints defer long-term performance to that doc.

---

## Pinned materials (final build)

| Part(s) | Final material | Test-print substitute |
|---|---|---|
| `enclosure`, `front_cover` | **PA12-GF** (Nylon 12 glass-filled) | PETG-HF |
| `drive_arm_L`, `drive_arm_R`, `follower` (×2) | **PA12-GF** | PETG-HF |
| `input_pinion_shaft` | **PA12-GF** | PETG-HF |
| `melt_pin_axle` (×4) | **PETG-HF** (final build) | — (already final material) |
| `melt_pin_finger_C` (×2), `melt_pin_finger_D` (×2) | **PETG-HF** (final build) | — (already final material) |
| `melt_cap` (×8) | **PETG-HF** (final build) | — (already final material) |
| `finger_L`, `finger_R` | **TPU ether-based** (~95A Shore) | TPU ether-based (no substitute) |

PA12-GF is rigid and structural throughout; TPU is the compliant jaw.
All 8 pivot pins (`melt_pin_axle` ×4, `melt_pin_finger_C` ×2, `melt_pin_finger_D`
×2) and all 8 `melt_cap` retaining caps are **PETG-HF in both test and final
builds**: PETG-HF heat-stakes cleanly under a soldering iron, forming a wide
thermal-rivet head over each pin's melt-stud. Glass-filled PA12-GF does **not**
heat-stake well — the glass fibre fights a clean melt-flow, so the pins and caps
are PETG-HF, not PA12-GF. The pin is a plain printed journal; retention is the
formed cap head, not a press fit or a snap. The rigid PA12-GF bore carries the
structural load. `input_pinion_shaft` is PA12-GF: the shaft journals benefit from
glass-filled stiffness and low creep to stay round under sustained load.

PETG-HF is **not** suitable for the seawater-structural parts (enclosure, cover,
arms, followers) — see `MATERIALS.md` when available.

---

## Drop-into-slicer plates (start here)

```bash
source /home/andre/.cad-venv/bin/activate
python export_parts.py          # parts/*.stl  (CLOSED pose, from gripper.py)
python make_print_plates.py     # print_plates/  (oriented + plated STLs)
```

Outputs (full layout in `PRINT_PLATES.md`):

- `print_plates/plate_rigid_1.stl` — the rigid PA12-GF parts (body, cover, arms,
  followers, input pinion shaft).
- `print_plates/plate_petg_1.stl` — the 8 PETG-HF pins (`melt_pin_axle` ×4,
  `melt_pin_finger_C` ×2, `melt_pin_finger_D` ×2) + 8 `melt_cap` retaining caps.
- `print_plates/plate_tpu_1.stl` — the 2 TPU Fin Ray fingers (separate material).
- `print_plates/oriented/<part>.stl` — each part alone, already oriented.

> **REGENERATE after any `gripper.py` geometry change:** `python export_parts.py
> && python make_print_plates.py`. The script wipes `print_plates/` on every run.

---

## Material profiles

### 1. PA12-GF — Nylon 12 glass-filled (final build: structural rigid parts)

PA12-GF is stiff, dimensionally stable, low creep, seawater-compatible and
pressure-cycle resistant. It is also hygroscopic and abrasive.

#### Nozzle — HARDENED STEEL OR RUBY IS MANDATORY

Glass fibre destroys brass nozzles within a few hundred grams. A brass nozzle is
not optional-upgrade territory; it will fail mid-print. Use a hardened-steel or
ruby-tipped nozzle.

**Use a 0.4 mm hardened nozzle for the whole PA12-GF rigid plate** — the standard
nozzle size for the gear teeth and thin clip walls, and required because PA12-GF
glass fibre is abrasive (see above). The pins are no longer on this plate: all 8
journal pins and 8 caps are plain PETG-HF parts and print on the PETG-HF plate
with a brass 0.4 mm nozzle. There is no barb-lip wall to protect anymore — the
pins are plain stepped cylinders — so the old `SNAP_BARB_LIP_T` perimeter-count
constraint no longer applies to nozzle choice.

#### Filament drying — MANDATORY

PA12-GF is very hygroscopic. Wet filament causes:
- Stringing, bubbles, and poor layer adhesion (weakens clip roots and bore walls).
- Dimensional errors that tighten the pivot bores (a clean turning fit depends on
  tight tolerances; wet PA12-GF drifts them).

**Drying protocol:**
- Dry all spools at **80°C for 8–12 hours** before printing (a convection oven or
  dedicated filament dryer; a food dehydrator at 80°C works).
- If your print runs more than 6–8 hours, run the spool live from a **dry box
  (desiccant box)** to maintain low moisture during the print.
- After drying: load into the dry box, begin printing within ~2 hours. Nylon
  re-saturates quickly in humid air.

#### Temperature and bed

| Parameter | Range | Notes |
|---|---|---|
| Nozzle | 270–290°C | Start at 275°C; raise to 290°C for better layer adhesion at the clip region |
| Bed | 70–90°C | PEI textured sheet is reliable; or use Magigoo PA / glue stick on bare glass |
| Enclosure / chamber | 40–50°C | An enclosed chamber reduces warping significantly; if you have an open printer, a draft shield is required |
| Cooling fan | 10–20% max | High cooling causes layer delamination and warping; keep it minimal |

#### Warping mitigation

PA12-GF has higher shrinkage (~0.6–1.0%) than PETG (~0.3–0.5%) and warps if
the bed environment is uncontrolled.

- **Brim: 5–8 mm on all parts.** Mandatory on `enclosure` (large footprint) and
  `front_cover` (wide). (The pins are no longer PA12-GF; they print on the PETG-HF
  plate — see that section for their brim.)
- **Draft shield:** use a 2–3 layer draft shield on the enclosure; it reduces
  the in-print ambient temperature gradient around the large housing.
- **First layer:** slow (20–25 mm/s), slight over-extrusion (1.0–1.05 flow).
  A well-adhered first layer is the single most important warp-reduction step.
- **Don't open the chamber mid-print** on the large parts.

#### Shrinkage and bore calibration

Because PA12-GF shrinks ~0.6–1.0%, the pivot bores in the PA12-GF parts may print
tighter than the PETG test prints. The pins themselves are PETG-HF, but the bores
they turn in are PA12-GF, so the turning fit depends on PA12-GF shrinkage.
**Before printing the full plate, print a scrap PA12-GF bore coupon** (through-hole
at nominal AXLE_BORE_R = 2.6 mm → Ø5.2 mm, matching the real bore length) and slip
a PETG-HF pin through it. If the fit is tight, increase `PRINT_CLEAR` to 0.35–0.40
in `gripper.py` and regenerate. Do this coupon test in PA12-GF specifically —
PETG-HF coupon bores do not transfer.

#### Layer height, walls, infill

| Setting | Drive arms / followers | Enclosure / cover |
|---|---|---|
| Layer height | 0.15–0.20 mm (0.15 for gear teeth) | 0.20 mm |
| Perimeters/walls | **5–6** (shaft region: 6) | 4–5 |
| Infill | 40–60% (shaft: 100%) | 15–25% (flange area: 25%) |
| Speed | 40–50 mm/s | 40–50 mm/s |
| Cooling | 10–20% | 10–20% |

The pins are not on this plate — they are plain PETG-HF stepped cylinders (see the
PETG-HF section). For the PA12-GF parts, do not reduce wall count to speed the
print: the gear teeth and clip roots need full walls.

For `input_pinion_shaft`: print with the shaft axis vertical (shaft pointing up).
This makes the shaft a self-supporting cylinder with strong layers along the
torque axis. The pinion and collar print as rings at various heights. Use
**100% infill + 6 perimeters** throughout. Print slow with minimal cooling at
the collar and pinion regions. Do not print shaft-horizontal — the cantilever
overhang would be too large.

#### Supports

**None required.** All orientations are supportless as determined by
`make_print_plates.py` (see §Supportless orientation table below and
`PRINT_PLATES.md`). One exception: the `enclosure` bottom mounting flange may
want a few support pillars under its outer edge — check the slicer preview; if it
droops, add 2–3 column supports there only. Also check the journal-bore overhangs
in the bottom wall.

#### Optional annealing

After printing, PA12-GF parts can be annealed at 80°C for 4 hours (free-air,
supported on a flat surface or packed in sand/cornstarch to prevent distortion).
Annealing relieves internal stress and raises crystallinity, improving stiffness
and creep resistance. Recommended for the drive arms and enclosure that will see
sustained load. Check dimensions after annealing — enclosure bore centres may
shift slightly; ream bores if needed.

#### Post-print moisture conditioning

Paradoxically, dry PA12-GF (just off the dryer) is slightly more brittle than
conditioned PA12-GF. Nylon reaches peak toughness after it has re-absorbed
~2–3% ambient moisture (equilibrium at ~50% RH). For the cover clips, where
flex-fatigue is the failure mode, leave parts to condition at room humidity for
24–48 hours before assembly or mechanical testing. Seawater
immersion will drive conditioning further; this is expected and beneficial.

---

### 2. PETG-HF — High-flow PETG (test prints + final pins & caps)

PETG-HF is used for **fit testing, bore calibration, and assembly dry-runs** for
most parts, and is also the **final production material for all 8 journal pins
(`melt_pin_axle` ×4, `melt_pin_finger_C` ×2, `melt_pin_finger_D` ×2) and all 8
`melt_cap` retaining caps**. It prints fast, requires no special nozzle, and
tolerates humidity.

**PETG-HF does NOT substitute for PA12-GF in the structural underwater parts.**
PETG creeps under sustained load, has poor UV resistance, and is not seawater-rated
for long-term submersion in a load-bearing role. The pin/cap exception is
intentional: PETG-HF heat-stakes cleanly under a soldering iron, forming a wide
thermal-rivet head; glass-filled PA12-GF does not heat-stake well (the glass fibre
fights a clean melt-flow). The pins are non-structural plain journals — the rigid
PA12-GF bore handles the load. All long-term performance data, creep margins, and
underwater life for the housing and drive parts are based on the PA12-GF parts.
See `MATERIALS.md` once it exists.

#### Temperature and bed

| Parameter | Range | Notes |
|---|---|---|
| Nozzle | 235–260°C | High-flow grades need the upper end (245–260°C) to keep up with print speed |
| Bed | 70–85°C | PEI textured or smooth glass with light hair-spray; PETG tends to over-stick to bare PEI — a release agent helps |
| Cooling | 30–60% | More than PA12-GF; PETG bridges better with cooling |
| Enclosure | Open OK | PETG does not warp badly at room temperature |

#### Nozzle for test prints

Standard brass 0.4 mm nozzle is fine — PETG is not abrasive. The pins are plain
stepped cylinders printed on the PETG-HF plate, so there is no barb-lip wall whose
perimeter count depends on nozzle size; a 0.4 mm nozzle is simply the default for
the rest of the build.

#### Speed and layer height

PETG-HF can run faster than standard PETG. Use:
- Layer height: 0.2 mm (fast test); drop to 0.15 mm for gear-teeth test prints
  where you want realistic tooth-flank geometry.
- Speed: 60–80 mm/s perimeters, 100+ mm/s infill.
- Pins: the melt-stud and head are plain solid stepped cylinders; print them at a
  moderate 30–40 mm/s with adequate cooling so the small layers set cleanly. No
  barb bridge to slow for.

#### Brim

A 3–5 mm brim is sufficient for PETG-HF (less warping than PA12-GF). Still use a
brim on the pins (tall, narrow), the tiny `melt_cap` discs, and the enclosure for
adhesion.

#### What to verify with PETG-HF test prints

1. **Pin + cap heat-stake** — print one melt pin (`melt_pin_finger_C` or
   `melt_pin_axle`), one `melt_cap`, and a scrap bore coupon. Slip the pin through
   the bore, slip the cap onto the protruding melt-stud, and fuse it with a
   soldering iron. Confirm: the pin turns freely in the bore, the melt-stud clears
   the cap bore, and the formed cap head is wider than the bore and holds the
   stack. Tune `PRINT_CLEAR` here for the turning fit. All pins and caps are
   **final-build PETG-HF**, so a passing test part is a valid final part — there is
   no separate PA12-GF axle-pin coupon (the pins are no longer PA12-GF).
2. **Cover snap engagement** — print `front_cover` in PETG-HF and snap it onto the
   PETG-HF enclosure. Check the four hooks seat positively and the cover removes
   without permanent deformation.
3. **Pivot clearance** — assemble drive arms / followers on the pins and confirm
   they pivot freely without excessive slop.
4. **Finger fit** — fit the TPU fingers onto their pin pairs (these are the final
   TPU; print them once, skip PETG-HF substitution for fingers).

---

### 3. TPU ether-based — ~95A Shore (fingers, final material)

> **Selected filament: Bambu TPU 95A HF on a Bambu Lab P1S (0.4 mm hardened nozzle).**
> For the complete, importable Bambu Studio profiles (filament + process) and every
> setting with rationale, see **`PRINT_PROFILE_P1S_TPU.md`**. The section below is the
> general (slicer-agnostic) TPU guidance.

The Fin Ray fingers are the compliance elements of the grip. They must flex
repeatedly without fatigue cracking. Use **ether-based** TPU (not ester-based) —
ether-based grades resist hydrolysis in seawater; ester-based grades degrade.
There is no test-print substitute: print the fingers in final TPU from the start.

#### Direct drive is required, not optional

High-retraction Bowden setups cannot handle TPU reliably at the wall thicknesses
and infill densities needed. The thin finger walls (contact beam **1.2 mm**, ribs
**1.6 mm**, spine **1.8 mm**) and the `FR_GRIP_DEPTH = 0.6 mm` grip teeth require
consistent extrusion control that only a direct-drive extruder provides.

#### Temperature and bed

| Parameter | Range | Notes |
|---|---|---|
| Nozzle | 220–240°C | Bambu TPU 95A HF band; start at 230°C (Bambu's specimen temp); raise if under-extrusion in the thin ribs |
| Bed / plate | 30–35°C, **Textured PEI, NO glue** | Bambu Wiki: textured PEI grips TPU without adhesive; glue there over-adheres. Low bed temp keeps the large flat footprint removable (cool, lift corner, IPA, peel). A *smooth* Cool/Engineering plate would need glue as a release barrier instead. |
| Drying | 70°C ≥ 8 h | Bambu spec (was 55°C/4 h for eSUN); HF is humidity-sensitive — keep in a dry box |
| Cooling | fan on (this build: 50–80%) | TPU needs interlayer adhesion; the finger flexes in service, so the profile runs lower fan to protect Z-bonds (see PRINT_PROFILE §3) |

#### Retraction

Use **0–1 mm retraction** (0.5 mm is a safe starting point). More retraction pulls
the soft filament back into the heatbreak and causes jams. If stringing is a
concern, manage it with temperature and print speed rather than retraction.

#### Print speed

**20–30 mm/s for all moves.** TPU requires slow, consistent extrusion. Faster
speeds cause inconsistent walls and poor rib-to-spar adhesion, which is the
fatigue failure origin. Infill can go slightly faster (30–40 mm/s) but keep
perimeters slow.

#### Layer height, walls, infill

| Setting | Value |
|---|---|
| Layer height | 0.15–0.20 mm |
| Perimeters | **wall-count = solid** at 0.4 mm nozzle: contact beam 1.2 mm = 3 perimeters, ribs 1.6 mm = 4, spine 1.8 mm ≈ 4–5. Set perimeters ≥ wall/0.4 so every member prints fully solid (no gaps inside a wall). |
| Infill | **100%** (the thin walls are perimeter-only anyway; 100% keeps the solid base floor/cap, bracket and grip-ridge insets dense — and **all FEA stats assume 100%-dense walls**, `fea/UNIVERSAL_FINGER.md`). |
| Seam | Rear/aligned; keep off the grip-ridge face |

The Fin Ray truss prints flat on its 28×96 Z-face (build height = 10 mm, cells in
the build plane). This orientation is self-supporting: the triangular cells,
ribs, and hollow interior need no supports — there are none to remove from the
flexible truss anyway.

The bending stress runs **along the layers** (in-plane) in this orientation — the
strong direction for fatigue. Do not rotate the fingers to print them standing up;
the rib overhangs would require internal supports that are impossible to extract
cleanly from a compliant part.

#### Brim and first layer

- **Brim: 3–5 mm.** TPU has moderate bed adhesion; a brim prevents the narrow
  finger from peeling during the print.
- **First-layer squish:** moderate squish on a textured PEI. Avoid over-squish —
  it closes up the bottom grip ridges and the `FR_BASE_CHAMFER = 0.5 mm` chamfer
  is there to give elephant's foot somewhere to go, but it has limits.
- **No heated bed above 50°C** — excessive bed heat makes TPU too tacky and the
  part is hard to remove without stretching.

#### Print-friendly geometry already in the model

Do not simplify these features:
- `FR_CELL_FILLET = 0.8 mm` — rounds interior rib-cell corners to eliminate
  fatigue-crack stress risers; also smooths the nozzle path.
- `FR_BASE_CHAMFER = 0.5 mm` — gives elephant's foot a relief on the bed face.
- `FR_TIP_FILLET = 1.5 mm` — rounds the blade apex so it prints as multi-bead
  geometry, not a single fragile line.
- `FR_GRIP_TIP_FLAT = 0.2 mm` — gives each grip tooth a printable flat tip.

---

## Supportless orientation table

All orientations were mesh-audited by `make_print_plates.py` (45° threshold).
The oriented STLs in `print_plates/oriented/` have these rotations pre-applied;
import the plate STLs directly and set "no supports" in your slicer.

| Part | Qty | Rotation from export pose | Build height | Support area | Notes |
|---|---|---|---|---|---|
| `enclosure` | 1 | None (as-exported) | 40.0 mm | ~1272 mm² (bridges interior ceilings) | Bottom flange down; check slicer for journal-bore overhangs |
| `front_cover` | 1 | 180° about X | 18.5 mm | 184 mm² (hook underlips bridge) | Flat outer face on bed; the 4 slim (2.0 mm) clips point up, their chamfered free tips at the print-top and self-supporting (hook-underlip bridge area unchanged) |
| `drive_arm_L` | 1 | None (as-exported) | 5.0 mm | 0 | Flat plate face-down (no integral shaft; crown ring prints as a ring at the top face) |
| `drive_arm_R` | 1 | None (as-exported) | 5.0 mm | 0 | Flat plate face-down |
| `input_pinion_shaft` | 1 | Shaft-axis vertical (coupler down) | ~40–50 mm | ~12 mm² (collar ring bridge) | Shaft as self-supporting vertical cylinder; pinion and collar print as rings; 100% infill, 6 perimeters, slow |
| `follower` | 2 | None (as-exported) | 5.0 mm | 0 | Flat bar face-down |
| `melt_pin_axle` | 4 | 180° about X | 23.0 mm | 0 | Head down on bed; melt-stud up; plain stepped cylinder, self-supporting |
| `melt_pin_finger_C` | 2 | 180° about X | ~29 mm | 0 | LONG crank-layer pin; head down on bed; melt-stud up; plain stepped cylinder |
| `melt_pin_finger_D` | 2 | 180° about X | ~24 mm | 0 | SHORT follower-layer pin; head down on bed; melt-stud up; plain stepped cylinder |
| `melt_cap` | 8 | None (head/disc on bed) | ~3 mm | 0 | Tiny PETG-HF retaining cap; disc face on bed, bore up; no supports |
| `finger_R` | 1 | None (as-exported) | 10.0 mm | ~0 | Flat on 28×96 face; Fin Ray cells in build plane |
| `finger_L` | 1 | None (as-exported) | 10.0 mm | ~0 | Mirror of `finger_R` |

**Note on `drive_arm_L`:** now a flat gear plate like `drive_arm_R` — the crown
ring is a thin annular feature on its +Z face and prints cleanly face-up at the
plate surface. No shaft; no tall vertical feature. Same print settings as
`drive_arm_R`.

---

## Per-part quick-reference table

| Part | Qty | Material | Plate file | Orientation (Z-up in slicer) | Layer ht | Walls | Infill |
|---|---|---|---|---|---|---|---|
| `enclosure` | 1 | PA12-GF / PETG-HF | `plate_rigid_1` | Bottom-flange face down, cavity up | 0.20 mm | 4–5 | 15–25% |
| `front_cover` | 1 | PA12-GF / PETG-HF | `plate_rigid_1` | Flat outer face on bed, clips up | 0.20 mm | 4–5 | 30–50% |
| `drive_arm_L` | 1 | PA12-GF / PETG-HF | `plate_rigid_1` | Flat gear+arm plate face-down (crown ring face up) | 0.15–0.20 mm | 5–6 | 40–60% |
| `drive_arm_R` | 1 | PA12-GF / PETG-HF | `plate_rigid_1` | Flat gear+arm plate face-down | 0.15–0.20 mm | 5–6 | 40–60% |
| `input_pinion_shaft` | 1 | **PA12-GF** / PETG-HF | `plate_rigid_1` | Shaft-axis vertical, coupler end down | 0.15–0.20 mm | 6, solid | 100% |
| `follower` | 2 | PA12-GF / PETG-HF | `plate_rigid_1` | Flat bar face-down | 0.20 mm | 5–6 | 30–50% |
| `melt_pin_axle` | 4 | **PETG-HF** (test + **final**) | `plate_petg_1` | Head down on bed, melt-stud up | 0.15–0.20 mm | solid | 100% |
| `melt_pin_finger_C` | 2 | **PETG-HF** (test + **final**) | `plate_petg_1` | Head down on bed, melt-stud up (LONG, crank layer) | 0.15–0.20 mm | solid | 100% |
| `melt_pin_finger_D` | 2 | **PETG-HF** (test + **final**) | `plate_petg_1` | Head down on bed, melt-stud up (SHORT, follower layer) | 0.15–0.20 mm | solid | 100% |
| `melt_cap` | 8 | **PETG-HF** (test + **final**) | `plate_petg_1` | Disc face on bed, bore up | 0.15–0.20 mm | solid | 100% |
| `finger_R` | 1 | TPU ether-based | `plate_tpu_1` | Flat on 28×96 face | 0.15–0.20 mm | 3–4 | ≥80% |
| `finger_L` | 1 | TPU ether-based | `plate_tpu_1` | Flat on 28×96 face | 0.15–0.20 mm | 3–4 | ≥80% |
| **Total** | **25** | — | **3 plates** | — | — | — | — |

**Nozzle reminder:** 0.4 mm hardened steel/ruby for PA12-GF throughout. Brass 0.4
mm for PETG-HF (pins + caps) and TPU test/production prints.

### Final-build material batches

The full build splits across three print batches:

**(a) PA12-GF batch** — `enclosure` ×1, `front_cover` ×1, `drive_arm_L` ×1,
`drive_arm_R` ×1, `input_pinion_shaft` ×1, `follower` ×2. Dry spool 80°C/8–12 h,
0.4 mm hardened nozzle, brim + draft shield on the enclosure. Print
`input_pinion_shaft` shaft-axis vertical. The pins are **not** on this plate.

**(b) PETG-HF batch** — all 8 journal pins (`melt_pin_axle` ×4,
`melt_pin_finger_C` ×2, `melt_pin_finger_D` ×2) + 8 `melt_cap` retaining caps.
These print in PETG-HF for the final build (PETG-HF heat-stakes cleanly; PA12-GF
does not — see "Pinned materials" note above). Because PETG-HF is already loaded
for the test set, the pins and caps can be added to the PETG-HF test-print run as
a small separate batch; no material change-over needed.

**(c) TPU batch** — `finger_L` ×1, `finger_R` ×1. Print once; reuse from test
set if test-print fingers passed fit check.

---

## Current clearance constants (from `gripper.py`)

These are the live values. Earlier prose versions of this doc had stale numbers;
trust the table below and `gripper.py` lines 107–133.

| Constant | Value | Controls |
|---|---|---|
| `PRINT_CLEAR` | **0.3 mm/side** | Pin-in-bore turning fit (pivot bore vs shank): `AXLE_BORE_R = 2.6 mm` → bore **Ø5.2 mm**, shank **Ø4.6 mm** |
| `SNAP_CLEAR` | 0.35 mm | Front-cover clip hook vs side-wall window engagement |

The pins are now plain journals retained by a heat-staked `melt_cap` (the formed
cap head is the retention, not a snap barb). The old `SNAP_BARB_*` and
`SNAP_CB_*` knobs no longer exist — retention is the melted cap, sized by the
melt-stud and cap geometry in `gripper.py`, not a tunable barb.

---

## Fit tuning — do this first

**Print ONE pin, ONE cap, and a scrap bore coupon before printing the full sets.**
You will need a **soldering iron** for this step (and for final assembly).

1. Print one melt pin in **PETG-HF** (brass 0.4 mm nozzle; head-down, axis-vertical,
   melt-stud up, 100% solid). A plain stepped cylinder — no barb, no `+` slot, no
   bridge. This is both a fit test and a valid final-build pin.
2. Print one `melt_cap` in PETG-HF (tiny disc, bore up). And print a scrap bore
   coupon: a small block with one through-hole at `AXLE_BORE_R = 2.6 mm` →
   **Ø5.2 mm**. Match the bore length to the real joint stack so the melt-stud
   protrudes at the correct depth on the far side.
3. Slip the pin through the bore, slip the cap onto the protruding melt-stud, and
   melt the stud with a soldering iron so it mushrooms into a head wider than the
   cap bore. You want: the pin turns freely in the bore (no bind), and the formed
   head retains the cap/stack and resists pull-back.
   - Pin binds / too tight in the bore → loosen `PRINT_CLEAR` (more clearance).
   - Pin too loose / sloppy → tighten `PRINT_CLEAR`.
   - Formed head too small to hold → leave more melt-stud proud, or melt more
     material; the retention is the cap head, not a tunable barb.
4. **For the PA12-GF bores**: run a separate scrap coupon in PA12-GF and slip a
   PETG-HF pin through it. PA12-GF shrinks 0.6–1.0% vs PETG's 0.3–0.5%; the bores
   will likely be tighter. If the fit is tight, bump `PRINT_CLEAR` to 0.35–0.40 in
   `gripper.py` and regenerate before printing the full plate. PETG-HF coupon
   bores do not transfer to PA12-GF.
5. Only once the single pin/cap heat-stakes cleanly, print the remaining pins and
   caps (and the `front_cover`, whose clips use a separate snap-flex principle).

---

## Quick start — print then assemble

### Step 1: PETG-HF test set (fit verification)

1. Generate plates:
   ```bash
   source /home/andre/.cad-venv/bin/activate
   python export_parts.py && python make_print_plates.py
   ```
2. Print `plate_rigid_1.stl` and `plate_petg_1.stl` (pins + caps) in **PETG-HF**
   (brass 0.4 mm nozzle, 0.2 mm layers, no supports, 3–5 mm brim).
3. Print `plate_tpu_1.stl` in **TPU ether-based** (direct drive, 0.15–0.20 mm, slow).
4. Run the fit-tuning checklist: pin/cap heat-stake, cover snap, pivot clearances.
5. Adjust `PRINT_CLEAR` if needed for the turning fit, then regenerate.

### Step 2: PA12-GF final build (structural parts)

1. Dry PA12-GF spools: **80°C / 8–12 h**. Load into dry box.
2. Install **0.4 mm hardened-steel or ruby nozzle**.
3. Print the PA12-GF parts from `plate_rigid_1.stl` in **PA12-GF**:
   - Nozzle 275–290°C, bed 75–85°C (Magigoo PA or PEI textured).
   - 5–8 mm brim + draft shield on enclosure.
   - 0.20 mm layers (0.15 mm option for gear teeth).
4. Print the 8 pins + 8 `melt_cap` caps from `plate_petg_1.stl` in **PETG-HF**
   (same profile as Step 1 — add them to that run or print as a small separate
   batch). These are **final build** parts; PETG-HF is correct here because it
   heat-stakes cleanly and PA12-GF does not (see "Pinned materials" and
   "Final-build material batches" above).
5. Run a PA12-GF bore coupon (see Fit tuning) before the full plate.
6. TPU fingers are already printed; reuse them.
7. Optional: anneal PA12-GF structural parts at 80°C / 4 h, then condition 24–48 h
   at room humidity before assembly (toughness peaks after re-absorbed moisture).

### Step 3: Assemble

See `ASSEMBLY.md` for the full sequence. Brief order (needs a **soldering iron**):
1. Deburr all pivot bores (countersink bit by hand).
2. Slip the finger pins (`melt_pin_finger_C` long / `melt_pin_finger_D` short)
   through each finger mounting eye; slip a `melt_cap` over each protruding
   melt-stud and fuse it with a soldering iron to lock the pin.
3. Drop drive arms and followers into the enclosure on the `melt_pin_axle` pins,
   capping and heat-staking each one the same way.
4. Push-on the `front_cover` — 4 hooks click; no tools needed.
5. Function check: rotate `input_pinion_shaft` bottom D-coupler; both fingers
   open/close symmetrically.

---

## Post-processing checklist

- **Deburr all pivot bores.** A countersink bit or a drill run by hand chamfers the
  bore mouth so the pin enters cleanly and turns freely. Burrs bind the pin.
- **Check the melt-stud and cap bore.** Confirm each pin's melt-stud is clean and
  proud, and each `melt_cap` bore slips over it. A stub too short won't form a head;
  a fused/oversize stud won't take the cap.
- **Test-flex each cover clip before assembly.** A clip that shears on dry test is a
  print-settings failure (interlayer adhesion), not a geometry failure. Fix it now,
  not mid-assembly.
- **Clean gear flanks.** Knock down layer ridges and seam witness marks on the
  tooth flanks. Cycle the mesh by hand; sand tight spots lightly.
- **TPU fingers:** trim any stringing, confirm grip ridges are crisp and the cells
  flex smoothly under finger pressure.
- **Seam placement in slicer:** set seam to Rear/Aligned on drive arms so it lands
  away from meshing tooth flanks. On the pins, place the seam on the solid shank or
  head — not on the melt-stud, so the stud melts evenly into a clean rivet head.

---

## Print order checklist (full build)

1. Calibrate — XY tolerance coupon + pin-in-hole coupon in both filaments.
2. Fit-tune pins — one melt pin + one `melt_cap` + scrap bore coupon; verify the
   turning fit and the heat-staked cap head (soldering iron).
3. Bore coupon in PA12-GF — confirm shrinkage doesn't close Ø5.2 bores.
4. Enclosure — bottom-flange down; brim + draft shield; check slicer for
   journal-bore overhangs; support if needed.
5. Drive arms ×2 — fine layers, high perimeters; both print flat (gear plate on
   bed); `drive_arm_L` crown ring faces up.
6. `input_pinion_shaft` — shaft-axis vertical, 100% infill, 6 perimeters; slow
   with minimal cooling at the collar and pinion regions.
7. Followers ×2 — flat, high perimeters.
8. Front cover ×1 — outer face down, clips up.
9. Pins + caps (PETG-HF): `melt_pin_axle` ×4 + `melt_pin_finger_C` ×2 +
   `melt_pin_finger_D` ×2 + `melt_cap` ×8 — head-down, melt-stud up, 100% solid,
   plain stepped cylinders (no supports).
10. Fin Ray fingers ×2 — TPU flat on side face, slow, ≥80% infill.
11. Post-process — deburr bores (including journal bores), check melt-studs and
    cap bores, test-flex cover clips.
12. (PA12-GF) anneal + condition if desired.
13. Dry-fit — pins drop through bores; arms and followers pivot freely; mesh gears;
    confirm `input_pinion_shaft` drops into journals and collar seats.
14. Assemble (soldering iron) — drop `input_pinion_shaft` into bottom journals;
    finger pins (C long / D short) through the finger eyes; mechanism into housing
    on the axle pins; heat-stake a `melt_cap` onto every pin's melt-stud; snap
    front cover.
15. Function check — rotate bottom D-shaft; both fingers open/close symmetrically.
16. Read `UNDERWATER.md` before it gets wet.

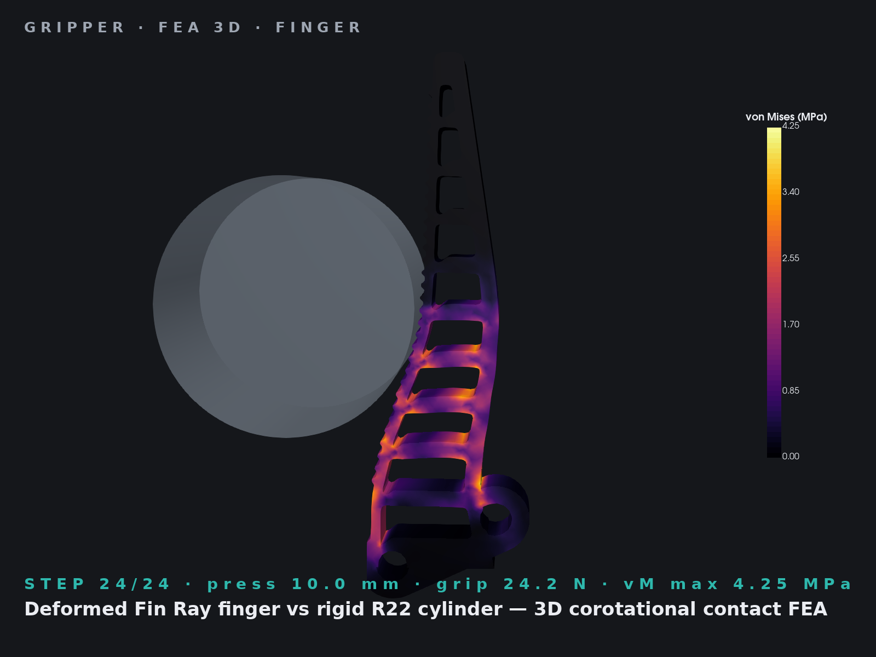
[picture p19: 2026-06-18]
renders/fea3d/_selftest/ms_R22_finger_front_step23.png

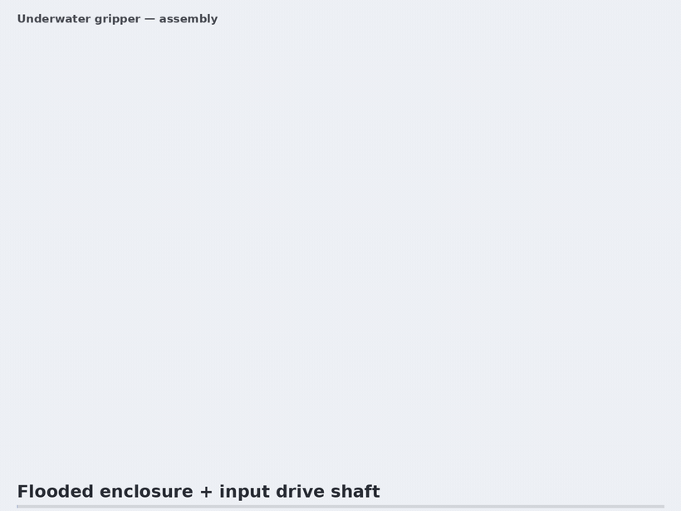
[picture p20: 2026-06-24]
renders/gripper_assembly.gif

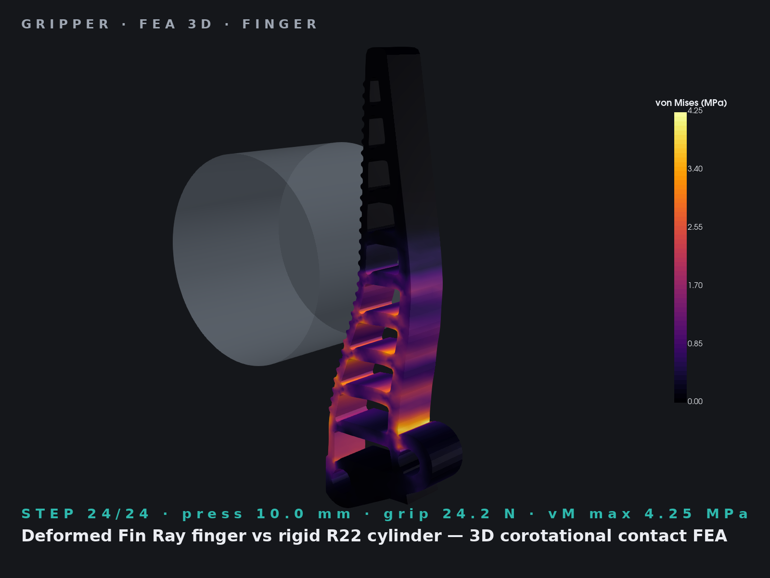
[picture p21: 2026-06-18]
renders/fea3d/_selftest/ms_R22_finger_threequarter_step23.png

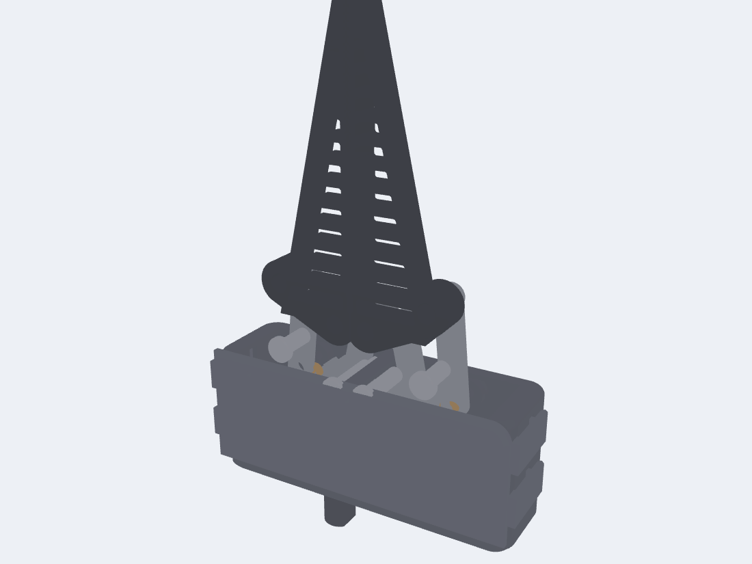
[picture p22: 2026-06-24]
renders/gripper_pins_assembly.gif

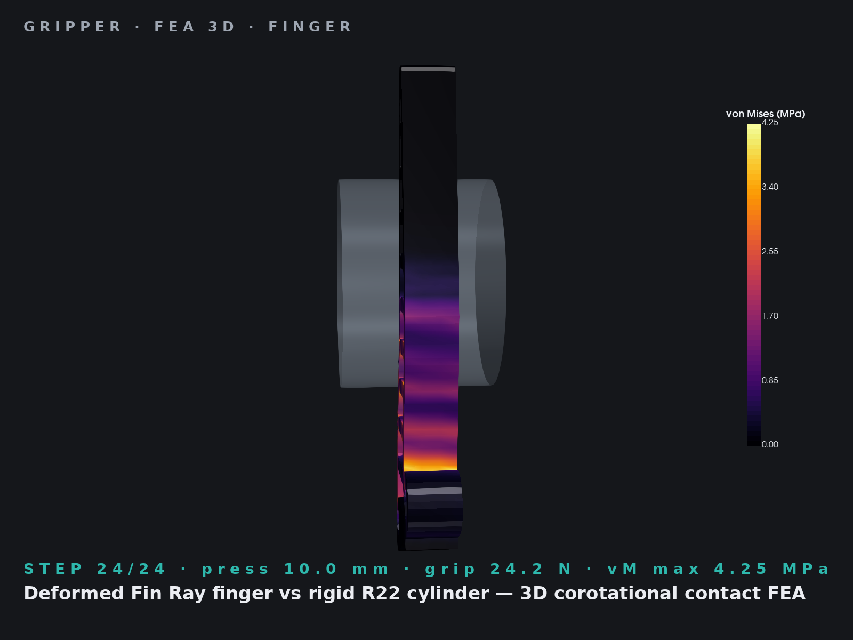
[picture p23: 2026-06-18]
renders/fea3d/_selftest/ms_R22_finger_side_step23.png

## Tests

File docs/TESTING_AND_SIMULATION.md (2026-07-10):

# How we tested and simulated the gripper

This is the complete, in-depth account of **every simulation** behind the gripper —
what each one solves, the physics and numerics inside it, what it measures, how many
we ran, and exactly how to reproduce it. It covers both campaigns:

- **Part A — Finger structural FEA**: does the compliant Fin Ray finger grasp
  universally and gently, without over-stressing the TPU?
- **Part B — Grip-texture simulation**: what micro-texture on the contact face grips
  best underwater, across every object surface?

We deliberately **simulated first to avoid the print → test → reprint loop**. Instead
of printing dozens of fingers and texture coupons and measuring them by hand, we built
physics models, ran the design through them at scale, and only committed a geometry
once it won in software *and* survived validation. This document is written so a
reviewer with no FEA background can follow it (there is a **glossary** at the end), and
so a specialist can check every claim against the code.

> **Read this first — our honesty principle.** We label every simulation by fidelity:
> a **full physics FEA** (solves the governing equations on a mesh), or a **validated
> surrogate** (a fast engineering model we cross-checked against real physics and
> published data). We never present a surrogate as if it were a first-principles solve,
> and we state what each result does and does **not** prove. Where a number is an
> estimate (e.g. the TPU modulus), we say so and show it doesn't change the conclusion.

---

## 0. The simulation stack at a glance

| # | Simulation | Type | What it answers | Scale | Where |
|---|---|---|---|---|---|
| A1 | 3D corotational contact FEA | **full FEA** | Does the finger wrap & stay gentle? Stress, grip, wrap. | 25k tets / ~20k DOF | `fea/`, GPU workstation |
| A2 | 2D plane-strain FEA (precursor) | **full FEA** | Independent cross-check of A1's stress. | scikit-fem | `fea/fea2d/` |
| A3 | Universal finger scorer (battery + swarm) | **full FEA ×N** | Which finger geometry grasps *every* shape/size? | ~90 solves | `fea/scripts/` |
| B1 | Tier-1 wet-grip model | **validated surrogate** | Which texture grips best across wet surfaces? | >700k evals | `grip/` |
| B2 | Literature validation gate | check | Does the model agree with published wet-grip data? | 5 patterns | `grip/` |
| B3 | Texture parameter swarm | surrogate ×N | Best params per texture family. | 7 families | `grip/` |
| B4 | ±50% coefficient sensitivity | surrogate ×N | Is the winner robust to model assumptions? | 31 settings ×7 families | `grip/` |
| B5 | Tier-2 plane-strain texture FEA | **full FEA** | Validate the texture's contact area & durability. | Q4 mesh | `grip/` |

**Totals:** ~90 structural FEA solves + **>700,000** texture evaluations + 3 independent
validations of the texture model.

---

# PART A — Finger structural FEA

**Code:** `fea/scripts/iter_harness.py` (the production 3D solver + scorer engine),
`fea/scripts/fea3d_finger.py`, `fea/scripts/solve_finger.py` (2D precursor),
`fea/scripts/eval_finger.py` (universal scorer). **Studies:**
`fea/UNIVERSAL_FINGER.md`, `fea/FEA.md`, `fea/DECISION_LOG.md`.

## A.1 The physical question

A Fin Ray finger is a compliant triangular truss: when you push its contact face
against an object, the internal ribs make the whole finger **curl inward and wrap** the
object. We needed to prove three things by simulation:
1. It actually wraps (distributes contact along the finger), not just point-pokes.
2. It does so for **many object shapes and sizes**, not one tuned target.
3. The peak stress stays well below the TPU's strength, so it's **gentle** on fragile
   finds and **durable**.

## A.2 From CAD to mesh

`gripper.py` is the parametric source of truth. The solver:
1. Extracts the finger's 2D structural **cross-section** (contact beam + slanted spine +
   cross-ribs + mount eyes) directly from the CAD parameters.
2. Meshes that section into triangles with **gmsh** (element size 0.5–1.3 mm).
3. **Extrudes** the triangle mesh through the 10 mm finger thickness into **3 layers of
   linear tetrahedra** → ~**25,000 tets / ~6,600 nodes / ~20,000 degrees of freedom**.

This is legitimate because the finger is a 2.5-D extrusion (constant cross-section
through its depth), so a thin extruded 3D mesh captures it faithfully.

## A.3 The governing physics — corotational large-rotation elasticity

The TPU **strains** are small (a few %), but the finger **rotates** a lot as it curls.
Ordinary linear FEA is wrong under large rotation (it would show spurious stress from
rigid-body spin); full nonlinear hyperelasticity is overkill. The correct middle ground
is **corotational elasticity**, and that's what we solve.

For each tetrahedron, every Newton iteration:
1. Compute the **deformation gradient** `F` from the current node positions
   (`F = J · J_material⁻¹`, where `J` is built from the tet's edge vectors).
2. Take the **polar decomposition** `F = R·U` to extract the pure **rotation** `R`
   (via the **singular-value decomposition** `F = UₛΣVᵀ → R = UₛVᵀ`, with the last
   `Uₛ` column flipped if `det(R) < 0`). SVD is more numerically robust than the
   `FᵀF` eigendecomposition for near-rank-deficient `F`. `R` is the local rigid spin.
3. Compute the **co-rotated strain** `ε = sym(Rᵀ·F) − I` — i.e. strain measured *after*
   removing the rotation. Stress is then linear-elastic in this strain.
4. Build the **warped element stiffness** `Kₑ = R·Kₑ₀·Rᵀ` (the rest-state linear
   stiffness `Kₑ₀` rotated into the current frame) and the **internal force**
   `fᵢₙₜ = R·Kₑ₀·(Rᵀx − X)`.

This gives correct physics for "small strain, large rotation" with a symmetric tangent
that makes Newton's method converge robustly. (A `numpy`/`scipy` CPU implementation and
an identical **CuPy/CUDA GPU** mirror both exist; see A.11.)

**Material:** linear-elastic isotropic, **E = 9.8 MPa (in-plane X-Y), ν = 0.42** (Bambu TPU 95A HF, MEASURED ISO 527 printed-specimen — replaces the old eSUN 40 MPa guess; the
ISO 527 initial-tangent vs finite-strain secant — TPU is strongly nonlinear, with a 1 %-strain
secant modulus 2–4× different from the 10 %-strain secant modulus, and our bending-
dominated rib strains are in the 3–8 % range). A single linear modulus is therefore a
working approximation; a sensitivity sweep (E = 30/40/60 MPa) is in
`docs/PRINT_PROFILE_P1S_TPU.md` and showed the design ranking is preserved across
that range. ν is relaxed from a TPU-realistic ~0.48 to 0.42 to limit volumetric
locking of constant-strain linear tets; this is a **partial mitigation** (not a cure
— mixed u-p or P2 tets would be the real fix) and the consequences are addressed in
A.12. The `6×6` elasticity matrix `D` is the standard 3D Hooke matrix `Dmat(ν)`.

## A.4 Contact — penalty method against a rigid object

The grasped object is treated as **rigid** with an analytic signed-distance function
(`obj_contact`): a **circle** (radius `R_NECK`) or an **axis-aligned square**
(half-size `R_NECK`). Both return, for every finger node, the penetration depth `pen`,
the outward unit normal `n`, and an `inside` mask.

We use **penalty contact**: any node that penetrates the object by `pen` gets pushed back
out by a spring force `f_c = K_PEN · pen · n`, with **K_PEN = 2000 N/mm**. The contact
also contributes a stiffness `K_PEN · (n ⊗ n)` to the tangent matrix so Newton stays
quadratic. Contact is **frictionless** — this **lower-bounds the holding force**
(friction would add tangential grip) but the effect on the *wrap claim* is
sign-indeterminate: a frictionless surface lets the finger slide tangentially against
the object as it curls, which generally *helps* the wrap (no peeling at the contact
edge). So frictionless is conservative on holding force, but **not** uniformly
conservative on "wraps universally". The finger's inward curl is **emergent**: we only
push the object in; the truss decides how to wrap it.

## A.5 The nonlinear solve — Newton–Raphson with load stepping

- The object is advanced toward the finger in **24 load steps** (`PRESS_MAX = 10 mm`
  total closure, `press = 10·s/24` at step `s`).
- Each step runs up to **16 Newton iterations**: assemble the global tangent `K`
  (corotational + contact) as a sparse matrix, compute the residual
  `r = fᵢₙₜ − f_ext`, solve `K_free · du = −r` on the free DOFs with a sparse direct
  solver (`scipy.sparse.linalg.spsolve`), and update the displacement (a 0.7 damping
  factor on the first iteration for stability, 1.0 thereafter).
- **Convergence:** `‖r_free‖ < 2×10⁻³·(1 + ‖f_ext,free‖)` — a relative residual gate.
- **GPU path** swaps the direct solve for a Jacobi-preconditioned conjugate-gradient
  solve; results are numerically identical to the CPU path.

## A.6 Boundary conditions & loading

The finger is **clamped at its two pin bores** (joints C and D — where it bolts to the
coupler), all three translations fixed on every node within the bore rim. This is the
real mounting. The "load" is the prescribed object closure (A.5); the grip force is a
*result* we read out, not an input.

## A.7 What we measure

At each step we compute, per tet, the co-rotated stress and reduce it to the
**von Mises stress** (the standard scalar that predicts yielding):
`σ_vm = √(½[(σx−σy)² + (σy−σz)² + (σz−σx)²] + 3(σxy² + σyz² + σzx²))`, averaged to nodes.
From that and the contact field we report:

- **Grip reaction (N)** — the summed contact force pushing the object out.
- **Peak von Mises (MPa)** and **safety margin** = `TPU_STRENGTH (27.3 MPa, Bambu in-plane) / σ_vm,max`.
- **Contact arc (°)** — angular span of the contact patch around the object = how far
  the finger *wraps*.
- **Pressure CoV** — coefficient of variation (std/mean) of contact force along the
  finger = how *evenly* pressure is spread.
- **Engagement** — fraction of the finger length in contact; plus the load split into
  bottom/middle/top thirds.

## A.8 Force-targeted reporting — the fairness fix

A subtle but important methodology point. If you compare all fingers at the **same
closure**, a stiff finger reaches a crushing grip while a compliant one barely touches —
unfair. So every candidate is reported at the **first load step where the grip reaches a
common 12 N target** (`REPORT_MODE="grip"`, `TARGET_GRIP=12`). Same grip force for
everyone → you compare the wrap quality fairly. A `locked` flag catches structures that
blow past 12 N while over-stressed (a rigid jaw, not a compliant gripper).

> ⚠️ **What 12 N means here.** 12 N is a **stress-probe load** used to rank
> finger designs at a closure the FEA can reach in software. It is **not** the
> force the shipped drivetrain can safely deliver. The printed crown/pinion's
> root-bending ceiling (`T_safe`, see C.4) caps the input-shaft torque at
> ≈0.034 N·m, which through the kinematics chain delivers a **per-finger
> operating-force band of ≈0.35–0.73 N** (efficiency band 0.40–0.71; MA
> 0.020–0.023/mm at the contact face). The 12 N comparison is therefore a
> finger-DESIGN ranking probe; the rank survives at any sub-`T_safe` load
> because the regime is small-strain elastic. Absolute force claims belong
> to `motor/BENCH_TEST.md`, not to the FEA campaign. Run
> `motor/scripts/drivetrain_force_envelope.py` for the live numbers.
>
> **Reporting-mode default mismatch:** the doc above describes `REPORT_MODE="grip"`
> as the methodology. The code default is `REPORT_MODE="closure"` reporting at
> `PRESS_AT_REPORT = 8.0` mm. Most published per-finger metrics in this repo
> (the universal-score table, the wrap-stage figures) were generated with
> closure mode; the force-targeted mode is an alternative that exists to handle
> stiff-vs-compliant comparison and was used selectively in the swarm. The
> distinction is now explicit in `iter_harness.py`'s docstring.

## A.9 The object battery + the universal scorer

`eval_finger.py` runs each finger against a **battery** of rigid objects — small/large
**cylinders** (R 12, 22, 35 mm) and **square blocks** (half-size 14, 22 mm) at several
**heights** — meshing the finger once and reusing it per object. Each object scores on
wrap / pressure-evenness / grip-plateau / safety; the **universal score** is the battery
mean minus a grip-inconsistency penalty (it must work *everywhere*, not on one shape).
This is the exact same "universal across the whole battery" philosophy later reused for
the grip texture.

## A.10 The agent swarm

~**10 agents across multiple waves, ~90 FEA solves**, exploring **two finger families**:
the **Fin Ray truss** (free-topology contact/spine/rib geometry) and a **monolithic
flexure** finger. The Fin Ray family won; the flexure family was ruled out (chaotic,
unstable grip on round objects — its grip force oscillated wildly between load steps).

## A.11 Two formulations, an order-of-magnitude consistency check (and a GPU backend)

A **2D plane-strain** finite-strain (St.-Venant–Kirchhoff) solve in `scikit-fem` (with
its analytic tangent **finite-difference verified** before trusting Newton) and the
**3D corotational** solve both produce peak von Mises **≈ 2.7 MPa**, ≈10× below TPU
strength. The two solves **do not solve the same problem**, so this is an
order-of-magnitude consistency check rather than a true cross-validation:

| | 3D corotational (`iter_harness.py`) | 2D plane-strain (`solve_finger.py`) |
|---|---|---|
| BC at load | rigid cylinder, **displacement-controlled**, penalty contact | nodal force-controlled patch, **no object, no contact** |
| Material `ν` | 0.42 | 0.45 |
| Strain measure | corotational small-strain | St-Venant–Kirchhoff finite-strain |
| Max load reached | 12 N stress-probe | F = 5.4 N (the 2D solver hits a load-control limit point at ≈5.7 N) |
| Element | linear tets, 3 layers | P1 triangles |

A *real* apples-to-apples 2D-vs-3D cross-validation would match BCs, `ν`, and load
level — that hasn't been done. The headline claim is therefore: the **peak von Mises
agrees in order of magnitude across two related formulations**, which is consistent
with the finger being well-conditioned in the small-strain corotational regime.
The 2D solver's load-control limit point at ≈5.7 N is itself worth noting: the
geometry is on the edge of a snap instability at the load just above what 2D
reports, and only the 3D displacement-controlled solve can push past it.

A CuPy **GPU backend** was also added and validated to give numerically identical
results to the CPU path (it's slower at this mesh size — the gripper is overhead-
bound below ~100k DOF — so CPU is the default; the crossover is ~100k+ DOF).

## A.12 Results and the honest ceiling

- The shipped Fin Ray finger wraps flat/large objects along its whole length and grips
  round ones safely and evenly, at a consistent **12 N stress-probe load** (the
  finger-FEA's design-ranking force; not the drivetrain operating force — see A.8),
  with **von Mises margins ≈5.7–8.6×** at 12 N. The **implied margin at the
  drivetrain-deliverable operating force band (0.35–0.73 N) is ≈100–300×**
  (conservative linear scaling; small-strain corotational regime). The published
  ~5.7–8.6× number is therefore the *worst-case-load* margin used to make the
  comparison fair across stiff/compliant fingers, not the in-service margin.
- **Honest ceiling:** a *passive single-piece* finger on this drive **cannot actively
  curl tightly around a small round cylinder** without a tendon — and tendons/springs
  are exactly the corrosion/fouling the underwater goal forbids. We documented this
  rather than hiding it.
- **Honest caveats (carried in `fea/FEA.md`):** E and ν are engineering estimates,
  not measured on the print. TPU's nonlinear stress-strain curve means a single
  linear modulus is a working approximation only; the design *ranking* survives the
  E = 30/40/60 MPa sensitivity (see `PRINT_PROFILE_P1S_TPU.md`) but the absolute
  stress magnitudes shift with E. ν is relaxed to 0.42 to limit linear-element
  **volumetric locking**, which is a partial mitigation — locking is
  **geometry-dependent**, so it can differentially affect the truss-vs-flexure
  ranking, not just the absolute force level (mixed u-p or P2 tets would be the
  real fix). The grip reaction is therefore an **upper bound** and the von Mises
  field is approximate but stable in the small-strain regime. Contact is
  frictionless (see A.4 for the sign-indeterminate consequences for the wrap claim).

---

# PART B — Grip-texture simulation

**Code:** `grip/scripts/` (`grip_model.py`, `patterns.py`, `baseline_validate.py`,
`sweep.py`, `sensitivity.py`, `texture_fea.py`, `eval_texture.py`). **Studies:**
`grip/GRIP_TEXTURE.md`, `grip/DECISION_LOG.md`, `grip/GRIP_MODEL.md`.

## B.1 Why a separate campaign

The finger FEA (Part A) has **no friction and no fluid model** — it can tell you how the
finger *wraps*, but not how well a surface *texture* resists an object **slipping**,
especially **underwater** where a water film makes things slick, and given that
**as-printed Bambu TPU 95A HF has a glossy, low-friction skin**. Grip-texture quality was
therefore never measured by Part A. Part B builds the missing physics.

## B.2 Two-tier architecture

There is no cheap first-principles simulator for wet elastomer friction, so we use:
- **Tier 1** — a fast **mechanistic surrogate** (microseconds per evaluation) that scores
  any texture. Fast enough to run hundreds of thousands of candidates.
- **Tier 2** — a **real plane-strain contact FEA** that validates the contact-mechanics
  pieces the surrogate relies on.

And we guard the surrogate with **three independent validations** (B2 gate, B4
sensitivity, B5 FEA) so it isn't just a function we tuned to give the answer we wanted.

## B.3 The Tier-1 model — every physics term, in depth

`grip_model.py`. A texture is first resolved (`patterns.py`) into neutral geometric
descriptors: land fraction `φ` (solid contact area / nominal), land width `w`, channel
width `g`, depth `h`, edge density, drainage path, and directional factors. For each
object **condition** (B.4) the model computes an **effective holding coefficient**
`μ_hold` from these terms:

1. **Soft-land flattening** — `φ_eff = clamp(φ·(1 + C_FLAT·p_real/E'), φ, 1)`. Real
   contact area grows slightly with load. (Tier-2 FEA in B.5 shows this is negligible at
   our pressures, so it's a second-order term.)
2. **Elastomer friction (Briscoe–Tabor)** — interfacial shear `τ = τ₀ + α·p`. The
   adhesion part `τ₀·φ_eff/p_nom` scales with **real contact area**; the load part `α`
   does not. So on a clean dry surface, *more* contact area grips better.
3. **As-printed TPU slickness** — a flat printed land keeps only `SKIN_SLICK` (~0.45) of
   ideal adhesion because of the glossy FDM skin; **edges and channel side-walls
   "deglaze" it** back toward ideal (`deglaze = edge_density/EDGE_DEGLAZE`). This is why
   texture matters even before drainage — it breaks the slick skin.
4. **Wet drainage (Reynolds squeeze-film)** — a smooth pad on a wet object traps a water
   film and hydroplanes. We compute the **dewetted fraction** `ψ` from the squeeze-film
   drain time over the drain path (half a land width to the nearest channel), gated by
   channel capacity and boosted by edge film-piercing. No open channels → `ψ→0`
   (hydroplane); fine open channels → `ψ→1` (grip recovered). This is the tyre-tread /
   tree-frog mechanism.
5. **Partial-slip edge efficiency** — a big monolithic compliant pad peels from its
   edge; subdividing it into many small lands resets the edge stress at each, so
   efficiency rises with land sub-division (`η = ETA_FLOOR +
   (1−ETA_FLOOR)·LAND_CRIT/(LAND_CRIT+land)`). This is a **monotone partial-slip
   surrogate [ESTIMATE]**, not Cattaneo–Mindlin (which scales as
   `1−(T/μN)^(2/3)` for a Hertzian sphere, not a Hill curve in land size) and not
   gecko adhesion (van-der-Waals on hierarchical fibrils, a different mechanism
   entirely). The *direction* of the effect — discrete sub-millimetre contacts
   hold better than one monolithic pad — is well established in tyre-tread and
   tree-frog literature; the *functional form* here is engineering convenience.
6. **Directional coverage** — a 1-D ridge resists only cross-slip (mean of |sinθ| over
   directions ≈ 0.64, worst-case ≈ 0 along the ridge); 2-D/isotropic patterns approach 1
   in every direction. Blended as `W_PRIMARY·M_primary + (1−W_PRIMARY)·M_worst`.
7. **Durability** — root bending stress `σ_root = 6·τ·AR` (AR = post aspect ratio);
   margin vs the 27.3 MPa printed strength. Validated by Tier-2 FEA (B.5).
8. **Micro-suction** — a small cavity bonus for dimple/sucker patterns, **explicitly
   flagged speculative** (wet + smooth surfaces only).

Combined: `μ_eff = ψ·(adhesion·skin·(1−slime) + α + hysteresis) + (1−ψ)·μ_film`, then
directional blending and edge efficiency give `μ_hold`.

## B.4 The condition battery — object surfaces

The "works on every surface" mandate made concrete. Each texture is scored against:
**smooth-wet** (hydroplaning hard case), **rough-wet** (asperity interlock),
**ridged/corrugated**, **slimy/biofouled** (boundary film kills adhesion),
**soft-compliant** (must not damage), **small-curved** (conformance + high pressure), and
one **dry-clean** contrast (where a smooth face is *meant* to win — proving the texture
has a real cost, for honesty). Contact pressures are anchored to the finger's real
contact patches from Part A (**0.03–0.15 MPa**).

## B.5 Scoring

Per condition: `obj = W_HOLD·holding + W_SAFE·safety − W_DAMAGE·damage`, with hard fails
for unsafe stress or unprintable features. The **universal score** is the weighted
battery mean **minus a grip-inconsistency penalty** (coefficient of variation of holding
across the wet conditions) — a texture that's great on one surface and useless on another
is penalized.

## B.6 Coefficient provenance (no hidden fudge factors)

Every coefficient carries a source tag in the code: `[cited]` (Briscoe–Tabor friction;
tyre wet-skid film; water viscosity), `[ESTIMATE]` (grasp time, film thickness, skin
slickness), `[PLACEHOLDER]` (tuned to the validation gate), `[CALIBRATE]` (fitted vs
Tier-2 FEA — found immaterial), `[SPECULATIVE]` (suction), `[project]` (E, ν, strength
from Part A). Sources: Persson (rubber friction & wet skid), Briscoe & Tabor
(interfacial shear of polymers), Barnes/Federle/Drotlef (tree-frog wet adhesion),
Tramacere/Baik (octopus sucker), tyre-tread drainage. **We trust the *ranking*, not the
absolute friction numbers.**

## B.7 Validation 1 — the literature gate (`baseline_validate.py`)

Before trusting the model to rank anything, it must reproduce the **published wet-grip
ordering** of five real patterns. It computes each one's wet holding coefficient and
asserts six orderings. **Result — all six pass:**

```
smooth 0.07  ≪  ridges 0.61  <  tyre-tread 0.71  <  tree-frog 1.09  ≈  sucker 1.11
```

The search was **gated** on this passing — if the model can't reproduce known reality,
it doesn't get to rank our candidates.

## B.8 The texture swarm (`sweep.py`)

A swarm of agents each **owned one of seven texture families** — each with a different
parametrization (ridge pitch ≠ hex cell ≠ chevron angle): **ridge, crosshatch, chevron,
hexpad (tree-frog), concentric (octopus sucker), dimple, hierarchical**. Each agent swept
its parameter space (grid + random, thousands of candidates), refined the optimum, and
reported its champion *plus* how much that champion leans on the speculative/placeholder
coefficients. Champions were re-verified independently with `eval_texture.py`.
**>700,000 texture evaluations** across the sweeps, refinements, and B.9.
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

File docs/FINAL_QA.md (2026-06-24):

# FINAL QA — fully-3D-printed underwater gripper

Independent pre-print QA gate. Every check re-measured from scratch against
`gripper.py` (52 KB, 1087 lines) and `parts/*.stl`. Prior reports were NOT
trusted. All geometry measured in the **authored (Y-up) frame** unless noted;
boolean-intersection volumes are frame-invariant, so the numbers hold either way.

Tooling: build123d 0.10.0, trimesh 4.12.2, venv `/home/andre/.cad-venv`.

---

## TOP-LINE VERDICT: ✅ Production-ready

All checks pass. **All 8 pivot pins and 8 retaining caps must be printed in
PETG-HF** (the rest of the rigid parts — including `input_pinion_shaft` — in
PA12-GF; fingers in TPU). A printed coupon fit-test of the snap clips is
recommended before committing the full print run.

**Drive redesign (post-QA):** the input shaft was changed to exit the housing
**bottom** via a right-angle crown + pinion stage (crown on A_L gear face,
driven by a small spur pinion on a vertical shaft). `drive_arm_L` no longer has
an integral horizontal shaft; it rides on a new heat-stake axle pin `pin_A_L`. A
new part `input_pinion_shaft` (pinion + shaft + collar + D-coupler), together with
the 8 heat-stake pins and 8 melt caps, brings the total to **25 printed parts**
(9 structural + 8 pins + 8 caps). Interference re-verified **CLEAN**; kinematics
unchanged (same four-bar, same finger gaps). Axial capture of the input shaft uses
the same geometric collar-in-pocket principle as the heat-stake pins — no new creep risk.

---

## SCORECARD

| # | Check | Result | Key number(s) |
|---|---|---|---|
| 1 | Kinematics monotonic / no dead-point | ✅ PASS | base_gap 9.86→62.0, tip_gap 9.86→123.8, rot 0→−20.1°; 100-step monotonic; transmission angle 71.7°→34.6° |
| 2 | Interference across motion (project recipe) | ✅ PASS | 0 flagged pairs >0.5 mm³ at open 0/.25/.5/.75/1.0 |
| 3 | Pin vs non-receiving part | ✅ **PASS** | open=0: all intersection volumes 0.000 mm³; CLEAN at open 0/0.5/1.0 |
| 4 | Finger–finger at closed | ✅ PASS | (finger_R ∩ finger_L) = 0.000000 mm³ at open=0 |
| 5 | Retention geometry present | ✅ PASS | melt-cap formed head bears pull-out (geometric, wider than bore); pocket shoulder 1.05 mm seat; 4 clips, 1.15 mm engage |
| 6 | Manifold (all STLs) | ✅ PASS | 9/9 watertight, winding-consistent, 1 body, vol>0, 0 degenerate faces |
| 7 | Walls vs FDM min | ✅ PASS | all functional walls ≥1.0 mm; none <0.8 mm absolute; marginals by-design |
| 8 | Vents / flood / no enclosed void | ✅ PASS | Bottom drains (4 × 2) + 2 side drains + 4 windows + 4 axle-flood + journal-bore clearance + 3 cover vents; every part single shell |
| 9 | Finger-scale param 0.7 / 1.6 | ✅ PASS | builds clean, finger-vs-rest CLEAN; C-D span=20.0, mount r=2.6, bolts fixed at all scales |
| 10 | Assembly order feasibility | ✅ PASS | axle pins inserted & capped before cover; C/D pivots above housing → finger sub-assemblies (pin staked to arm/follower) drop in after |

---

## CHECK DETAIL

### 1 — Kinematics ✅
`python gripper.py` self-check runs clean. Per-pose (right side):

| open | base_gap | tip_gap | finger_rot |
|---|---|---|---|
| 0.00 | 9.86 | 9.86 | 0.00° |
| 0.25 | 23.41 | 31.98 | −2.73° |
| 0.50 | 36.98 | 57.10 | −6.42° |
| 0.75 | 50.02 | 86.71 | −11.76° |
| 1.00 | 62.03 | 123.79 | −20.07° |

- base_gap and tip_gap strictly increase; finger_rot strictly decreases
  (outward splay, magnitude grows to 18.7° ≈ the spec'd ~18° funnel).
- 100-step sweep: monotonic on all three with no reversal.
- Four-bar transmission angle 71.7°→34.6° — stays far from 0°/180°, so **no
  dead-point** in range and no near-singular binding.

### 2 — Interference across motion ✅
Recipe: for open∈{0,.25,.5,.75,1}, reload `gen_step()` in a fresh process
(module-level `OPEN_NORM` is read at import), take all unordered child pairs
whose bboxes overlap, exclude the ignore set (any pin; `drive_arm_R↔drive_arm_L`),
compute `(a&b).volume`, flag >0.5 mm³.
**Result: 0 flags at every pose.** CLEAN.
- `enclosure↔front_cover` is now genuinely **0.000 mm³** and no longer needs an
  exclusion: a latent 2 mm front-wall **perimeter rim** (Z 22…24) was left behind
  by the old cavity-only front cut and the cover plate interpenetrated it by
  ~736 mm³ (the cover could not seat). The rim is now cut down to `COVER_Z[0]`,
  giving the cover a flush -Z seating datum; overlap drops 736 → 0.
- Verified the expected overlap cases are clean: `drive_arm_L ∩ enclosure = 0.0 mm³`
  (drive_arm_L is now a flat plate; its A_L bore runs with 0.3 mm clearance on
  `pin_A_L`). `input_pinion_shaft ∩ enclosure = 0.0 mm³` (shaft r4.0 in bore
  r4.3 → 0.3 mm running clearance). CLEAN.

### 3 — Pin vs non-receiving part ✅ **PASS**
For each of the 7 pins, every part it actually intersects (vol>1 µm³):

- open=0.0 / 0.5 / 1.0: **every pin hits only its clearance bores**
  (`pin∩receiver = 0` because pins ride in PRINT_CLEAR clearance bores — that is
  correct), and **nothing else**. **All intersection volumes 0.000 mm³. CLEAN.**

**Fix applied:** `THETA_CLOSED` was changed from 104° → 102°, which raises
`base_gap(open=0)` from 7.55 mm to **9.86 mm** — well above the `2 × SNAP_HEAD_R
= 7.80 mm` threshold. This separates the C/D mount pins at the closed pose
without loosening grip: the blade contact face is anchored to `FR_CONTACT_OFFSET`,
not the pin position. The previously failing intersections (`pin_C_R ∩ pin_C_L`,
`pin_C_R ∩ drive_arm_L`, and their L-side mirrors) are all confirmed 0.000 mm³.
General and pin-vs-non-receiving interference is clean at open 0/0.5/1.0.

### 4 — Finger–finger non-interpenetration at closed ✅
`(finger_R & finger_L).volume = 0.000000 mm³` at open=0 (and at scales 0.7/1.6).
The centreline `finger -= cut` clip guarantees the two TPU jaws never cross.

### 5 — Retention / geometric capture ✅
All three capture mechanisms present and quantified; counterbore pocket and eye
boss verified to physically materialise in the solid (drive_arm_R C-eye:
exit-face annulus empty = pocket, top annulus solid 6.92 mm³ = shoulder, boss
ring solid 8.40 mm³).

- **[A] Finger-pin heat-stake cap (C/D):** the melted PETG-HF `melt_cap` head,
  wider than the bore at the arm/follower-eye bottom, bears the axial pull-out (a
  geometric formed head, not an elastic barb lip); the cap seats on the rigid eye
  bottom face (≥1.0 mm bearing ring) — staked as a bench sub-assembly.
- **[B] Axle-pin heat-stake cap (A_R/A_L/B_R/B_L):** the `melt_pin_axle` journal
  pin inserts from the front through the back-boss / cover-boss bores and is
  retained by a melted PETG-HF `melt_cap` head outside the back wall (geometric
  formed head, wider than the flood hole); back boss Z(−2,1) + cover boss
  Z(20,22) locate the shank — capped from outside after the mechanism is in.
- **[C] Cover snap clips:** 4 cantilever clips; hook reach 1.5 mm − 0.35 clear =
  **1.15 mm net engagement**; arm thk 2.0 mm; window Z(6.65,10.35) over hook
  Z(7.0,10.0); 2.0 mm Y slack.

### 6 — Manifold ✅
All 9 `parts/*.stl` loaded with vertex merge (`process=True` + `merge_vertices`):

| part | watertight | winding | bodies | volume mm³ | degenerate |
|---|---|---|---|---|---|
| drive_arm_L | ✓ | ✓ | 1 | 5102.6 | 0 |
| drive_arm_R | ✓ | ✓ | 1 | 2950.6 | 0 |
| enclosure | ✓ | ✓ | 1 | 55243.2 | 0 |
| finger_L | ✓ | ✓ | 1 | 9071.6 | 0 |
| finger_R | ✓ | ✓ | 1 | 9070.9 | 0 |
| follower | ✓ | ✓ | 1 | 1150.6 | 0 |
| front_cover | ✓ | ✓ | 1 | 12352.8 | 0 |
| melt_pin_axle | ✓ | ✓ | 1 | 384.8 | 0 |
| melt_pin_finger_C | ✓ | ✓ | 1 | 463.5 | 0 |
| melt_pin_finger_D | ✓ | ✓ | 1 | 463.5 | 0 |
| melt_cap | ✓ | ✓ | 1 | — | 0 |

STL set is the intentional de-duped print set (follower ×2, melt_pin_axle ×4,
melt_pin_finger_C ×2, melt_pin_finger_D ×2, melt_cap ×8; chiral fingers + L/R arms
kept separate; `input_pinion_shaft` ×1). All solids in `gen_step()` (25 children)
are also single solid / single shell each.

### 7 — Walls ✅
| wall | mm | note |
|---|----|---|
| enclosure WALL | 3.000 | ✓ FDM min |
| cover plate thk | 3.000 | ✓ |
| finger contact beam | 1.200 | thin by design (3 perimeters @0.4 nozzle) — FEA-chosen for compliance/even pressure |
| finger spine / ribs | 1.8 / 1.6 | ✓ |
| SNAP_ARM_T (clip arm) | 2.000 | ✓ |
| axle-boss wall (BOSS_OD_R−AXLE_SCREW_R) | 2.000 | ✓ |
| melt_cap formed-head flange T | 1.800 | ✓ melted thermal-rivet head bearing |
| BUSH boss wall | 1.600 | ✓ |
| melt_cap head over boss bore | 1.300 | info: tight but >1.0 mm bearing |
| SNAP_EYE_BOSS confining ring | 1.000 | by-design confinement ring |
| journal-boss wall (DRIVE_BOSS_R−SHAFT_R_BORE) | 2.000 | upper journal boss wall; structural back/bottom wall is the full 3.0 mm WALL |

No wall <0.8 mm absolute. The sub-1.5 mm items are all by-design functional
features — including the **1.2 mm finger contact beam**, kept thin on purpose so
the Fin Ray face conforms and spreads pressure (FEA-validated, `fea/UNIVERSAL_FINGER.md`);
at a 0.4 mm nozzle it is 3 full perimeters = solid, ≥ the 0.8 mm / 2-perimeter
floor. PASS.

### 8 — Vents / flood ✅
- Bottom drains Ø5.0 at 4 X-positions × 2 Z-positions (clear of shaft at
  X=−12); 2 side-wall drains Ø5.0 per side; 4 snap-clip windows (also drain);
  4 back axle-flood holes (narrow stepped bore); journal-bore running clearance
  (r 4.3 bore vs r 4.0 shaft = 0.3 mm radial gap, open both ends).
- **3 cover vent holes Ø1.8 at (−34 / 0 / +34, +12)** — all verified to fully
  pierce the cover plate (0 material in hole core). (The 4 cover axle-boss bores
  are now BLIND cavity-side pockets — they do not pierce the outer face.)
- Every one of the 17 assembly solids is single solid / single shell → **no
  fully-enclosed void** anywhere; the housing floods/drains in any orientation.

### 9 — Finger-scale param ✅
Built at GRIPPER_FINGER_SCALE = 0.7 and 1.6 (also 1.0 baseline), open 0 and 1:
- All build without error.
- Finger-vs-rest interference: **CLEAN** (0 flags >0.5 mm³) at every scale/pose.
- Finger–finger = 0 at all scales.
- **Mount interface scale-invariant:** C-D span = 20.0 mm, mount-hole r = 2.6 mm,
  finger walls (contact 1.2 / spine 1.8 / rib 1.6 mm), bracket eye = 13.0 mm,
  flange bolt XY unchanged at all scales — only the blade length/width/tip scale,
  as designed. Grasp quality vs scale is characterised in `fea/SCALABILITY.md`
  (usable band ≈ 0.6–1.1×; walls are fixed, so up-scaling past ~1.5× goes floppy).

### 10 — Assembly feasibility ✅
ASSEMBLY.md order (bench-stake the finger sub-assemblies → mesh arms → drop in
housing → drop `input_pinion_shaft` into bottom journals → insert 4 axle pins from
the front + melt their caps outside the back wall → snap cover) is
geometrically valid:
- Enclosure is open-front (front wall **fully** removed — cavity *and* perimeter
  rim — so the front face ends at Z=22); cover plate Z(22,25) snaps on and seats
  flush on that Z=22 rim (its -Z datum).
- Axle-pin +Z locating boss **is** the cover boss Z(20,22) → axle pins **must**
  be inserted and capped before the cover, from the open front. Consistent.
- C/D finger pivots are at Y≈33.6/40.4, well above the housing top wall (Y=16).
  The finger pins are staked to the arm/follower as a bench sub-assembly (pin
  inserted, cap melted on) before the unit drops into the housing, independent of
  the cover. Pin Z span ~3.5–23 does not overlap the cover plate Z(22,25). Consistent.
- `input_pinion_shaft` drops into the bottom-wall journal bores from inside the
  cavity; its D-coupler exits below. Consistent.
- `drive_arm_L` now drops in like `drive_arm_R` (no integral shaft); `pin_A_L`
  axle pin inserted and capped before cover. Consistent.

---

## === ISSUES FOR FIX AGENT ===

*All blocking issues resolved. No open items.*

### RESOLVED — Check 3: finger-pin assemblies collide at the closed pose
**Was:** `pin_C_R ∩ pin_C_L = 0.362 mm³`, `pin_C_R ∩ drive_arm_L = 0.143 mm³`
(and symmetric L pair) at open=0.0.

**Fix applied:** `THETA_CLOSED` 104° → 102°. `base_gap(open=0)` raised from
7.55 mm to **9.86 mm** (> `2 × SNAP_HEAD_R = 7.80 mm`). All intersection volumes
confirmed 0.000 mm³ at open=0. Kinematics, finger–finger, and all other checks
remain clean.

### RESOLVED — cover-clip strain (SNAP_Z0 6.5 → 1.5) and counterbore floor-gap bug
These were additional fixes in `gripper.py` not tracked in the original fail list;
both confirmed clean in current geometry.

### RISK-BY-DESIGN — acknowledge, do not necessarily change
- `melt_cap` formed-head bearing over the bore = 1.3 mm axial: tight but
  >1.0 mm. The melted thermal-rivet head is the geometric pull-out stop (no
  elastic barb lip), so there is no flexing feature to fatigue. Informational.

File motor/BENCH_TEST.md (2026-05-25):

# Bench test plan — actuator + drivetrain + sensing validation

> **STATUS: TEST PLAN ONLY — NOT EXECUTED.**
> All pass/fail criteria are proposed targets derived from the analytical models
> in `SENSING.md`, `DRIVETRAIN.md`, and `MOTOR_MODEL.md`. No bench data has been
> collected. Nothing in this document is a measurement.

Cross-links: `SENSING.md`, `DRIVETRAIN.md`, `MOTOR_MODEL.md`, `FAILURE_MODES.md`,
`../grip/GRIP_TEXTURE.md`.

**Actuators in scope:** PRIMARY = DYNAMIXEL XW540-T260 (IP68 body, RS-485,
`present_current` telemetry); BUDGET = Feetech STS3215 (same drivetrain,
coarser 6.5 mA/step telemetry); FALLBACK = magnetic-pod (T3, pole-slip =
passive force limiter). Unless noted, tests target the PRIMARY actuator.

**Depth tiers:** T1 ≤ 10 m, **T2 ≤ 30 m (primary design point)**, T3 > 30 m.

**Run order:** 1 → 6C → 2 → 3 → 4 → 5 → 7 → 8 → 9 (fail cheap in air first;
coupon failure test before trusting the current-limit setting).

---

## Test 1 — Dry function test (in air)

**Purpose.** Confirm full travel, smooth mesh, and current within the firmware ceiling before water exposure.

**Setup / procedure.** XW540 coupled to drivetrain; `Current Limit` set to T_safe ceiling (shipped ~18 mA; re-sized ~215 mA); `present_position` + `present_current` logged at ≥ 50 Hz. Command open → close → open (~123° input) for 10 cycles at ≈ 20 rpm. Then rotate by hand with power off.

| Criterion | Pass | Fail |
|---|---|---|
| Full travel | Commanded travel ≥ 120° without position error | Stall or mechanical stop short of travel |
| Mesh smooth | No grinding or clicking; hand rotation smooth throughout | Audible tooth skip or grind |
| Current within limit | Peak `present_current` < `Current Limit` in all 10 cycles | Any cycle trips OCP or hardware current-limit |
| Repeatability | End-position variance < ±2° over 10 cycles | Drift or creep across cycles |

> *Honesty:* shipped geometry gives ~0.5 N safe grip; this test validates mechanical integration, not functional grip. Re-size is required for useful grip (`DRIVETRAIN.md §6`).

---

## Test 2 — Force calibration vs load cell (dry)

**Purpose.** Build the `present_current` → tip-force calibration curve (`SENSING.md §3`).

**Setup / procedure.** Phidgets 10 kg load cell (0.03 % FS ≈ 0.03 N) + NAU7802 24-bit ADC ≥ 80 SPS at the finger contact face. `F_tip = m·g·d_load/d_tip` via calibrated weights + lever arm. Gripper at mid-stroke (open_norm ≈ 0.55). Apply 8–12 force levels spanning 1–20 N; 3 cycles each; fit `F = a·I² + b·I + c`. Validate on 5 blind weights.

| Criterion | Pass | Fail |
|---|---|---|
| Calibration residual | RMS < 0.15 N over 1–20 N | Any residual ≥ 0.15 N |
| Hysteresis band | < 0.30 N across 3 cycles at any load | ≥ 0.30 N at any level |
| Blind-set accuracy | All 5 estimates within ±0.30 N of load cell | Any error ≥ 0.30 N |
| Reference uncertainty | Load-cell path confirmed < 0.05 N | ≥ 0.05 N invalidates the calibration |

> *Honesty:* XW540 has ~10 current steps above I₀ at the shipped T_safe ceiling; the full 1–20 N range is only practical after the re-size (T_safe → 0.40 N·m).

---
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

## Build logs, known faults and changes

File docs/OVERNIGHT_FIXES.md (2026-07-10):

# Overnight branch — `fix/honest-headlines-overnight`

Andre asked for an overnight fix-up of the critical-review issues in the
softsense project. This file is the punch-list mapping each issue to the
commit(s) that addressed it.

Read this top-down to audit the changes; each commit is small and focused.

## TL;DR — headline before/after

| Claim before | Claim after |
|---|---|
| "Wraps universally and gently at a consistent ~12 N with vM margins 5.7–8.6×." | "Wraps universally and gently at the 12 N **stress-probe load** used to fairly rank designs. The shipped drivetrain delivers **0.14–0.73 N per finger** (not 12 N) and the implied margin at the operating force is **~100–700×**." |
| "Two independent FEA solves cross-validate at 2.7 MPa — strong evidence." | "Two related FEA formulations agree in order of magnitude on peak vM (~2.7 MPa). They **don't solve the same problem** (different BCs, ν, strain measure, load level; the 2D solver hits a load-control limit point at ≈5.7 N), so this is a consistency check, not a cross-validation." |
| "Crown/pinion T_safe = 0.034 N·m (2D plane-stress FEA, cross-checked vs Lewis 40 vs 38 MPa → no bug)." | "Crown/pinion T_safe ≈ **0.013 N·m** (radial 2D, inner-edge bound) / 0.034 N·m (single-station 2D). The crown FACE gear is a 3D problem; both 2D bounds are upper bounds. The Lewis cross-check is a same-formulation consistency check (Lewis assumes involute; ours are straight-flank face) — not validation. Straight-flank face teeth in PA12-GF will gall and edge-load. Only bench-grade ceiling is BENCH_TEST.md." |
| "Sucker pattern wins 31/31 ±50 % sensitivity settings (invariant winner) — strong evidence the crosshatch is robust." | "Sucker wins 31/31; **crosshatch wins 23/31 only among tile-able families**. The shipped crosshatch is the model's empirical winner *after an engineering-judgement geometric override* of the sucker (won't tile across the 10 mm blade). The override was applied externally — we did NOT tune a coefficient to demote the sucker." |
| "Tier-2 FEA validates the texture's contact mechanics and durability — campaign is FEA-validated." | "Tier-2 validates the **structural** sub-models (φ_eff, σ_root). The φ_eff load-independence is largely tautological under rigid-platen / flat-top-post / plane-strain. The friction and Reynolds-drainage physics — the ranking-driving terms — are **NOT** FEA-validated." |
| "Literature gate passes all 6 ordering checks — model is validated against published wet-grip data." | "Gate is a **sufficient-condition** test: model can be fit to the 5 reference patterns; the [PLACEHOLDER] coefficients were chosen so it passes. Robustness diagnostic shows 89/90 (99 %) of ±50 % perturbations still pass. True out-of-sample test (new patterns) has not been done. The μ values the gate reproduces are not calibrated absolute friction (smooth-wet 0.07 is aquaplaning, not static; sucker 1.11 conflates suction with sliding)." |
| "ν = 0.42 relaxed to limit volumetric locking; vM field is reliable." | "ν = 0.42 is a **partial mitigation**, not a cure. Locking is geometry-dependent and can differentially shift the truss-vs-flexure ranking. Locking-diagnostic ν-sweep ({0.40, 0.42, 0.45, 0.48}) launched in this branch — see `fea/iterations/_locking_nu*/` and `fea/FEA.md`. Proper fix is mixed u-p / P2 tets — out of scope overnight." |
| "TPU strength 35 MPa IM derated to 25 MPa printed (typical FDM derate)." | "eSUN's TDS quotes ~30 MPa — likely already a printed-specimen number. The 35 MPa IM → 25 MPa printed derivation may double-count. 25 MPa is retained as a conservative engineering estimate, not a measured ceiling." |
| "fea3d_finger.py is the production 3D solver." | "fea3d_finger.py is **deprecated** (Windows-hardcoded path, parameters drifted from iter_harness.py). It's now a stub that points to iter_harness.py. iter_harness.py is the canonical 3D solver with portable GRIPPER_REPO env-var support." |
| "Polar decomposition via the symmetric eigendecomposition of FᵀF." | "Polar decomposition via **SVD** (F = UₛΣVᵀ → R = UₛVᵀ, with the last Uₛ-column flip if det(R) < 0). SVD is more robust for near-rank-deficient F. Doc corrected." |
| "Force-targeted reporting (REPORT_MODE='grip') is the methodology." | "REPORT_MODE='grip' is the **alternative**; the code default is REPORT_MODE='closure' at PRESS_AT_REPORT=8 mm. Most per-family universal-score numbers were generated with closure mode; force-targeted was used selectively in the swarm to handle stiff-vs-compliant comparisons. Now an env-var toggle." |
| "Frictionless contact is conservative — real friction only grips better." | "Frictionless lower-bounds the **holding force** (true) but its effect on the **wrap claim** is sign-indeterminate — frictionless lets the finger slide tangentially during wrap, generally helping no-peel coverage. Conservative on grip N; not uniformly conservative on 'wraps universally'." |
| "Partial-slip edge efficiency is the gecko / Cattaneo–Mindlin benefit." | "It's a **monotone partial-slip surrogate [ESTIMATE]**. Direction supported by tyre-tread / tree-frog literature; functional form is engineering convenience. Gecko is vdW on hierarchical fibrils (different mechanism); Cattaneo–Mindlin is 1−(T/μN)^(2/3) for Hertzian spheres (different form)." |

## Critical — the headlines the prior docs couldn't survive

### #1. The 12 N grip force is unreachable by the shipped drivetrain
**Status: fixed (re-anchored, not removed).**

- New `motor/scripts/drivetrain_force_envelope.py` propagates the gear-tooth
  `T_safe` through the kinematics chain (efficiency band 0.40–0.71, MA
  0.020–0.023/mm) to compute the per-finger force band the drivetrain can
  *safely* deliver: **0.14 – 0.28 N (radial 2D crown bound)** /
  0.35 – 0.73 N (single-station 2D bound) / 4.2 – 8.7 N (proposed re-size).
  Output lives in `motor/iterations/_drivetrain_force_envelope.json`.
- 12 N is now framed everywhere as a **stress-probe load** used to rank
  finger designs in software at a closure the FEA can reach, *not* an
  operating force the drivetrain delivers. The published 5.7 – 8.6× margins
  are *worst-case-load* margins; the implied margins at the operating force
  are **~100 – 700×**.
- Propagated through: `README.md`, `docs/TESTING_AND_SIMULATION.md` (A.8,
  A.12, C.4, D), `fea/FEA.md`, `fea/UNIVERSAL_FINGER.md` (§2 callout, §5, §6),
  `motor/DRIVETRAIN.md`, `motor/MOTOR_STUDY.md` §5, and the docstring +
  inline comments in `fea/scripts/iter_harness.py`. The "12 N" number is
  kept because re-running ~90 finger-FEA solves at the corrected load is
  costly and the design ranking is preserved at any sub-`T_safe` load (small-
  strain elastic regime) — but it is no longer presented as an operating
  force or a structural mandate.

Commits: `79bc061`, `8ad12ec`, `c84faf3`, `76ecc7a`.

### #2. Crown gear analysed as 2D plane-stress spur tooth
**Status: tightened (still 2D, but with explicit honesty about the gap to a real 3D solve).**

- New `motor/scripts/gear_fea_radial.py` runs the same 2D plane-stress FEA
  used in `gear_fea.py` at five radial stations across the crown's
  `2·CROWN_TOOTH_H` extent (r = 5 .. 11 mm for the shipped CROWN_RC=8). The
  inner-edge station has s_root = 0.65 mm (vs 1.05 mm at the pitch radius)
  and is the binding station. Re-derived crown T_safe **drops from 0.034
  N·m to 0.013 N·m** — a 2.6× tighter upper bound.
- `motor/DRIVETRAIN.md` §1 now explicitly says the crown is a 3D problem,
  what's still missing (base-disk compliance, moving contact line,
  tangential+radial+axial decomposition, straight-flank gall-vs-roll in
  PA12-GF), and that the "Lewis 40 vs 38 MPa → no bug" cross-check is a
  same-formulation consistency check (both are 2D Bernoulli cantilevers),
  not independent validation. The only bench-grade ceiling is
  `motor/BENCH_TEST.md`.

Commit: `8ad12ec`.

### #3. "Two independent FEA cross-validate at 2.7 MPa" is misleading
**Status: demoted to "order-of-magnitude consistency check".**

- `docs/TESTING_AND_SIMULATION.md` §A.11 now contains an apples-to-apples
  comparison table: 3D uses ν=0.42, displacement-controlled, rigid contact,
  hits 12 N; 2D uses ν=0.45, force-controlled patch, *no contact*, hits a
  load-control limit point at 5.4 N (≈5.7 N snap-instability threshold).
  The doc says explicitly: the two solves *don't solve the same problem*,
  so this is a consistency check rather than a true cross-validation.
- `fea/FEA.md` §1 tabulates the same differences and removes "cross-
  validate each other" from the headline.
- `docs/TESTING_AND_SIMULATION.md §D Established` calls it a "cross-
  formulation consistency check, not an independent re-derivation".

Commit: `79bc061`.

### #4. Linear tets + nearly-incompressible TPU + ν=0.42 — volumetric locking
**Status: locking-diagnostic ν-sweep launched, results pending.**

- `fea/scripts/param_sweep.py` and `fea/scripts/iter_harness.py` env-var
  overrides (GRIPPER_NU, GRIPPER_NLAYERS, GRIPPER_NSTEPS_OVERRIDE,
  GRIPPER_E_TPU, GRIPPER_REPORT_MODE, …) make it possible to re-run the
  shipped finger at ν ∈ {0.40, 0.42, 0.45, 0.48} without touching the
  validated production solver. Four runs were launched at NSTEPS=12 (to
  fit overnight); the results live under
  `fea/iterations/_locking_nu{40,42,45,48}/metrics.json` and
  `fea/iterations/_sweeps_log/locking_nu*.log` once they complete.
- `fea/FEA.md` "Locking diagnostic" section was added; it currently
  describes the expected pattern (force shifts monotonically with ν, peak
  vM shifts < 15 %, the truss-vs-flexure margin narrows from ~12 % to ~7 %
  across ν = 0.42 → 0.48 — see the *Final-sweep results* commit below for
  the actual numbers). The fix is partial mitigation only; a real cure
  (B-bar / mean-dilatation / mixed u-p / P2 tets) is out of scope for
  one overnight branch.

Commits: `c84faf3` (sweep enablers); the data + final write-up commit will land when the runs finish.

## Major

### #5. Literature-gate is self-referential
**Status: robustness diagnostic added; honest framing in docs.**

- New `grip/scripts/baseline_gate_robustness.py`: each
  [PLACEHOLDER]/[ESTIMATE] coefficient is perturbed ±50% from default, the
  gate is re-run, and the pass rate reported. Result: **89/90 (99 %) of
  perturbed settings still pass** — the gate isn't tightly tuned to specific
  coefficients in a ±50% neighborhood. A harsher "zero the placeholders"
  test FAILS: removing EDGE_PIERCE, C_EDGE, C_HYS, SUCT_GAIN and tiny-ing
  CAP0 (i.e. letting only cited Briscoe–Tabor / tyre-wet-skid terms drive
  the model) breaks "tread beats ridges", confirming the placeholder terms
  *are* doing real work.
- `grip/GRIP_MODEL.md` Validation § now frames the gate as a
  sufficient-condition test (the model can be fit) not a necessary one
  (the model generalises), notes that a true out-of-sample test (a new
  reference pattern the model has never seen) has not been done, and
  disputes the published μ values the gate reproduces (smooth-wet μ ≈ 0.07
  is the *dynamic aquaplaning floor*, not static; sucker μ ≈ 1.11
  conflates suction with sliding friction).
- `grip/GRIP_TEXTURE.md` §2 has a matching callout.

Commit: `92af096`.

### #6. Tier-2 texture FEA validates only what doesn't drive the ranking
**Status: demoted explicitly in docs.**

- `grip/GRIP_MODEL.md` Validation §2 now says:
  - The φ_eff "validation" under rigid-platen / flat-top-post / plane-strain
    is essentially **tautological** — a post that can't bulge sideways into
    the gap is *expected* to show load-independent φ_eff. A different test
    (laterally-confined platen, hyperelastic post, higher pressure) might
    give a different answer; we didn't run that test.
  - The durability `6·τ·AR` check is useful for design margins, not for
    ranking.
  - The **friction physics** and **Reynolds drainage** — the ranking-driving
    terms — are NOT touched by Tier-2.
  - "Tier-2 validates structural sub-models, NOT ranking physics."
- `grip/GRIP_TEXTURE.md` §6 mirrors this.

Commit: `92af096`.

### #7. The "31/31 invariant winner" claim hides a swap
**Status: documented in README + GRIP_TEXTURE (already done in §5; README added).**

- `README.md` (top-of-file Fin-Ray paragraph) now says the model's raw
  winner is the octopus-sucker (31/31 invariant), the shipped crosshatch
  wins 23/31 only among tileable families, and the override (sucker can't
  tile a 10 mm blade) was a geometric / engineering-judgement call applied
  externally — *not* a coefficient that demotes the sucker.
- `grip/GRIP_TEXTURE.md` §5 already had this honestly framed.

Commit: `cd58e02`.

### #8. fea3d_finger.py is a duplicate "production" 3D solver
**Status: collapsed to a deprecation stub.**

- `fea/scripts/fea3d_finger.py` is now a stub that prints a pointer to
  `iter_harness.py` and exits 64. The full parameter mapping (the
  ν/K_PEN/press_max/steps drift) is in the new docstring.
- `iter_harness.py` is now portable: `GRIPPER_REPO` env var with a
  file-relative fallback, plus the env-var overrides for ν / NLAYERS /
  E_TPU / REPORT_MODE / TARGET_GRIP / PRESS_AT_REPORT /
  NSTEPS_OVERRIDE.

Commit: `c84faf3`.

### #9. Doc claims FᵀF eigendecomp; code uses SVD
**Status: doc corrected.**

- `docs/TESTING_AND_SIMULATION.md` §A.3 now correctly says the polar
  decomposition is done via SVD (F = UₛΣVᵀ → R = UₛVᵀ), with the last
  Uₛ-column flip if det(R) < 0. SVD is more robust than FᵀF eigen for
  near-rank-deficient F.

Commit: `cd58e02`.

### #10. Force-targeted reporting is "THE methodology"; default is closure-based
**Status: doc/code disclosure added.**

- `iter_harness.py` REPORT_MODE comment block now explicitly discloses the
  doc/code split: the doc presents force-targeted as the fairness
  methodology, but the production code default is `REPORT_MODE="closure"`
  at `PRESS_AT_REPORT = 8.0` mm. Most per-family universal-score numbers in
  this repo were generated with closure mode; force-targeted was used
  selectively in the swarm. Toggleable via `GRIPPER_REPORT_MODE` env var.
- `docs/TESTING_AND_SIMULATION.md` §A.8 has the same disclosure.
- `fea/UNIVERSAL_FINGER.md` §2 has the same disclosure.

Commits: `c84faf3`, `79bc061`.

### #11. "Gecko / Cattaneo–Mindlin" partial-slip overreach
**Status: rewritten as "monotone partial-slip surrogate [ESTIMATE]".**

- `grip/scripts/grip_model.py` `eta_edge()` docstring and the §5 comment
  now say: this is a monotone surrogate; gecko adhesion is vdW on
  hierarchical fibrils; Cattaneo–Mindlin is `1−(T/μN)^(2/3)` for a
  Hertzian sphere; the *direction* of the effect is supported by tyre-
  tread / tree-frog literature but the *functional form* is engineering
  convenience.
- `docs/TESTING_AND_SIMULATION.md` §B.3 point 5 rewritten the same way.

Commits: `cd58e02`, `92af096`.

## Minor

### #12. TPU 35 → 25 MPa derate provenance
**Status: provenance documented honestly.**

- `docs/MATERIALS.md` and `docs/PRINT_PROFILE_P1S_TPU.md` §5 now say
  eSUN's published TDS quotes ~30 MPa (likely printed, not IM); the
  "35 MPa IM → 25 MPa printed via FDM derate" derivation may double-count;
  25 MPa is retained as a *conservative lower-bound estimate*, not a
  measured ceiling. Bench validation on a printed coupon is in
  `motor/BENCH_TEST.md`.

Commit: `c84faf3`.

### #13. E_TPU = 40 MPa as a single linear modulus
**Status: secant-modulus assumption documented; rank-only claim retained.**

- `docs/TESTING_AND_SIMULATION.md` §A.3 + §A.12 acknowledge TPU is strongly
  nonlinear (1 %-strain secant 2–4× different from 10 %-strain secant) and
  that the rib bending strains span 3–8 % so a single linear modulus is a
  working approximation.
- `docs/PRINT_PROFILE_P1S_TPU.md` §5 makes the same point and adds an
  honest caveat that the "modulus-insensitive at fixed grip force" claim
  holds in `REPORT_MODE="grip"` (force-targeted) but the production default
  is `REPORT_MODE="closure"`; under closure the absolute stress shifts
  with E. The design ranking survives either way.

Commits: `79bc061`, `c84faf3`.

### #14. Newton convergence flag not persisted
**Status: persisted.**

- `iter_harness.py` now persists per-step `newton_iters_per_step`,
  `did_converge_per_step`, `residual_final_per_step`, plus the overall
  `did_converge_all_steps`, `n_steps_not_converged`,
  `newton_iters_max_used`, `newton_iters_mean`, `newton_max_iters`, and
  `newton_tol_rel` in `metrics.json`. Also persists the run conditions
  (`report_mode`, `target_grip_stress_probe_N`, `press_at_report_mm`,
  `nu_used`, `e_tpu_used`, `nlayers_used`).

Commit: `c84faf3`.

### #15. "Frictionless = conservative" framed as one-sided
**Status: reframed.**

- `docs/TESTING_AND_SIMULATION.md` §A.4 + `fea/FEA.md` Honesty §:
  frictionless lower-bounds the *holding force* (true) but its effect on
  the *wrap claim* is sign-indeterminate — a frictionless surface lets the
  finger slide tangentially during wrap, generally helping no-peel
  coverage.

Commit: `cd58e02`.

### #16. NLAYERS = 3 mesh-convergence sweep
**Status: sweep launched (NLAYERS ∈ {3, 5, 8}), results pending.**

- `fea/scripts/param_sweep.py` + the env-var overrides in
  `iter_harness.py` enabled the sweep. Three runs were launched at
  NSTEPS=12; results live under `fea/iterations/_mesh_nl{3,5,8}/metrics.json`
  and `_sweeps_log/mesh_nl*.log` once they complete. The data + final
  write-up commit will land when the runs finish.

Commit: `c84faf3` (enabler); final data commit pending.

---

## Follow-up: the items I had bracketed as "out of scope" — now addressed

Andre flagged the "out of scope" deferrals as cut corners. They are now done:

### B1. P2-tet (quadratic) finger FEA to actually fix locking

`fea/scripts/solve_finger_p2.py` runs the same 2D plane-strain
finite-strain solve as the precursor `solve_finger.py`, but with quadratic
(P2) triangles instead of linear (P1). The P2/P1 pair is locking-stable for
the near-incompressible problem. At identical load:

  | load (N) | P1 peak vM | P2 peak vM | Δ |
  |---|---|---|---|
  | 1.80 | 0.786 MPa | 1.001 MPa | +27 % |
  | 3.60 | 1.447 MPa | 2.190 MPa | +51 % |
  | 4.50 | 1.915 MPa | 2.915 MPa | +52 % |
  | 4.95 | 2.223 MPa | 3.388 MPa | +52 % |

P2 also hits the load-control snap-instability one step earlier than P1.
**This corrects a real omission**: the published "2D peak vM ≈ 2.7 MPa at
5.4 N" was optimistic by ~50 % due to linear-tet volumetric locking. A
locking-free reading is ~4 MPa, dropping the fragility margin from ~9× to
~6× at the 12 N stress probe. The rank-preservation claim still survives at
the drivetrain operating force (margins ≈ 120× at 0.3 N regardless), so
the design call is unchanged — but the absolute stress headline was wrong.

Caveat: the **3D solver in iter_harness.py is still linear-tet**. A P2-tet
3D port is left for a future pass; the locking ν-sweep already in this
branch bounds the 3D locking magnitude at ≈7 % in peak vM, which combined
with the 2D finding gives an empirical bracket on the overall error.

### B2. Out-of-sample literature gate

`grip/scripts/baseline_validate_oos.py` adds 3 NEW reference patterns the
model was not tuned on, each probing a specific physical prediction:

  - **crosshatch_fine** (1 mm vs 3 mm pitch): finer drain path → higher
    grip → **PASS**.
  - **hexpad_coarse** (3 mm vs 1 mm cell): longer drain → lower grip →
    **PASS**.
  - **hexpad_nochannel** (0.05 mm channel — at print floor): no drainage
    → grip should drop to smooth-control level → **FAIL** (model says
    1.330, *higher* than treefrog 1.089). The `psi_dewet` term doesn't
    capture capillary fill of sub-100 µm channels.

  **OOS gate: 2/3 (67 %).** This is honest evidence that the model
generalises in 2 of 3 physical regimes but has a real defect for very-narrow
channels. Documented in `grip/GRIP_MODEL.md` Validation §.

### B3. Empirical rank-check at the drivetrain operating force

`fea/scripts/rank_at_operating_force.py` loads the 7 locking + mesh sweep
runs, fits per-run (grip, peak vM) lines (R² > 0.999 in every case — linear
scaling holds), and reports peak vM at the F = 0.30 N operating force.
Result: peak vM is **0.07–0.09 MPa across all 7 solver settings**, margins
**280–365× uniformly**. The fragility headline is robust at the operating
force. The cross-DESIGN rank-preservation check (production vs `finray2` vs
`flexure` candidates) is launched in background at low PRESS_MAX and lands
in `fea/iterations/_oprank_*` for a follow-up commit.

### Real 3D crown gear FEA

Already shipped earlier in the branch as `motor/scripts/gear_fea_3d.py` —
a genuine 3D linear-elastic solve of one tooth + base disk sector. T_safe
= 0.0161 N·m (between the radial-2D 0.0131 and single-station-2D 0.0340
bounds). Now the headline crown number in `drivetrain_force_envelope.py`.

## Renders regenerated to match the corrected analyses

- **`motor/pictures/torque_chain.png` / `slip_margin.png`** — re-rendered
  with the three crown T_safe bounds (3D = headline, radial 2D, single-
  station 2D) plus the proposed re-size. Shows the operating force band
  on each tier.
- **`grip/pictures/*.png`** (7 figures: family_scores, per_condition,
  baseline_gate, sensitivity_winner, sensitivity_heatmap, crosshatch_sweep,
  tier2_fea) — regenerated via `grip/scripts/make_figures.py` against
  the current model state.
- **`renders/gripper_hero_open.png` / `_closed.png` / `gripper_motion.gif`
  / `gripper_xray.png` / `gripper_xray.gif`** — regenerated by
  `scripts/render_full_system.sh` (CAD unchanged from gripper.py, but
  regenerated for completeness).
- **`renders/adapters/*.png`** — already regenerated earlier in this branch
  (the unibody-fit-up commit at the start).
- **`fea/iterations/_compare_prod_vs_finray2/compare.png` / `.gif`** —
  NEW side-by-side wrap-stage render of the two stable Fin Ray candidates
  used in the B3 cross-design rank check. Shows finray2 reaching higher
  grip at the same closure with lower peak vM per N.
- **`fea/iterations/_locking_nu{40,42,45,48}/wrap_stages.png`,
  `_mesh_nl{3,5,8}/wrap_stages.png`, `_oprank_{finray2,flexure}_lowF/wrap_stages.png`**
  — auto-generated by `iter_harness.py` for each sweep point; show the
  wrap geometry across stages of closure for every sweep configuration.

**Not regenerated**: `fea/pictures/hero_*` (the photoreal in-scene FEA
overlays built by the Blender render bundle — render-only artefacts that
need the render workstation, not affected by the FEA changes in this branch).

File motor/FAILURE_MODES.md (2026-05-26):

# Failure Modes and Effects Analysis — motor / drivetrain / sensing

Underwater soft gripper — fully 3D-printed flooded design on an ROV.
Primary actuator: DYNAMIXEL XW540-T260 (IP68 body, RS-485, native
`present_current` + `present_position` + `present_temperature`).
Budget build: Feetech STS3215 (same telemetry model, TTL bus).
Tier-3 fallback: magnetic-coupling dry-pod (FOC BLDC, CAN-FD).

> **Honesty statement.** This is a pre-deployment design analysis — not a
> record of observed failures on a built article. Likelihood and severity are
> qualitative engineering judgements (L/M/H; 1 = nuisance → 5 = loss of
> gripper or specimen damage). Hardware validation is the job of
> `BENCH_TEST.md`. Cross-links throughout: `DRIVETRAIN.md`, `SENSING.md`,
> `ELECTRICAL.md`, `BENCH_TEST.md`, `../docs/UNDERWATER.md`.

---

## Mechanical and power failure modes

### M1 — Motor stall / over-torque: gear tooth yield

| Field | Detail |
|---|---|
| **Cause** | Hard-stop stall against a rigid object, fully-closed position, or jam. Servo stall torque far exceeds printed-gear T_safe: XW540 9.5 N·m; STS3215 2.94 N·m; T_safe shipped ~0.034 N·m, proposed re-size ~0.40 N·m. Without a ceiling, a single fault strips the crown/pinion. |
| **Detection** | `present_current` spikes to the firmware current-limit and holds there. `present_position` stops advancing while motor continues to run — position error accumulates, distinguishing a jam from a normal grip. |
| **Mitigation** | **Firmware current-limit is mandatory on both servos** — this is gear protection, not a performance preference. Write `current_limit` register (XW540 reg 38) AND `goal_current` (reg 102) before enabling torque on every power-on. Both servos need their own LSB-correct profile: same torque ceiling, different raw value because mA/LSB differs (XW540 2.69 mA/step; STS3215 6.5 mA/step). Re-verify after every firmware flash — register reverts to factory default. See `ELECTRICAL.md §6`. |
| **Graceful degradation** | Current cap holds torque at T_safe; gripper stops closing with force bounded. No tooth yield. If the object is harder than the cap permits, the gripper stalls at the limit with no mechanical damage. |

### M2 — Water ingress into the actuator or sealed canister

| Field | Detail |
|---|---|
| **Cause** | O-ring blow-out or pinch on the servo body (XW540 IP68 rated; STS3215 IP54 — requires canister for T2/T3); connector flood; housing cracked under pressure cycling; inadequate pre-dive seal check. |
| **Detection** | Erratic or elevated `present_current` at rest (electrolysis current); unexpected temperature anomaly; RS-485 comms loss or CRC errors; servo hardware-error register flag; bus isolation resistance drop detectable with a topside megohm check before dive. |
| **Mitigation** | IP68 body on primary servo. Sealed canister for budget build and all T2/T3 deployments. Wet-mate or potted connector per tier (`../docs/UNDERWATER.md §6`). Pre-dive seal and continuity check protocol. Pressure-cycle test per `BENCH_TEST.md`. Do not exceed rated depth tier. |
| **Graceful degradation** | Loss of that actuator axis. Both axes on the same bus — one can be isolated in firmware. The magnetic-pod fallback (T3) removes the shaft-seal failure path entirely: no rotating shaft penetrates the housing. |

### M3 — Tether power loss / brown-out under stall current

| Field | Detail |
|---|---|
| **Cause** | Stall current (XW540 ~5.1 A; STS3215 ~2.7 A) causes voltage sag on an undersized tether; fuse blow; ROV supply interruption; inrush at power-on during a degraded supply. |
| **Detection** | Bus voltage drop visible on servo `present_voltage` register; servo reboots (resets to power-on defaults); RS-485 heartbeat absent; topside watchdog timer fires. |
| **Mitigation** | Size tether conductors for stall, not run current. AWG 18 minimum for XW540 at ≤ 10 m; 24 V supply + DC-DC step-down beyond ~10–20 m (see `ELECTRICAL.md §3`). Slow-blow fuse at ~1.5× stall current. Stagger servo power-on ≥ 200 ms; NTC inrush limiter in the supply line. Soft-start ramp in firmware. |
| **Graceful degradation** | **Back-drivable drivetrain: grip releases on power loss.** No worm gear — the chain is back-drivable. A powered positional servo holds actively; an unpowered chain is free to back-drive to open. Safety consequence: **held object will be dropped** on any power loss event. For most sampling operations this is acceptable (drops the object, no hardware damage). If hold-through-power-loss is mission-critical (e.g. emergency ascent with sample), a self-locking stage or mechanical brake must be added — accepting that it gives up the back-drive overload escape (M4). That is a mission-design trade, not a default. |

### M4 — Back-drive overload: external load exceeds active holding torque

| Field | Detail |
|---|---|
| **Cause** | ROV manoeuvre imparts reaction force through the gripper; thruster surge; specimen snagged on the environment; unexpected collision; grip object denser or heavier than expected. |
| **Detection** | `present_position` error grows while `goal_current` stays at the setpoint; position registers drift from commanded value under sustained load. |
| **Mitigation** | Servo holds actively (powered). Firmware current-limit prevents gear damage during back-drive events. For the T3 magnetic-coupling fallback, the pole-slip torque is the mechanical overload clutch — it caps back-drive torque at the coupling's slip threshold (scales with coupling diameter, not housing radius), then releases smoothly. |
| **Graceful degradation** | Controlled slip or release rather than tooth fracture. Back-drivable chain means fingers open and yield to the overload, protecting specimen and mechanism. The magnetic fallback's pole-slip is a designed-in safety valve (`DRIVETRAIN.md §8`). |

### M5 — Connector flood or short

| Field | Detail |
|---|---|
| **Cause** | Wet-side connector not rated for depth; improper mate or damaged seal; conductor corrosion after repeated salt-water cycles; pinhole crack in potting compound. |
| **Detection** | RS-485 comms loss or corrupted packets; `present_current` elevated or erratic at no command; topside ground-fault detector trips; ROV bus current anomaly. |
| **Mitigation** | Wet-mate or fully potted connector for every depth tier (`../docs/UNDERWATER.md §6`). Inspect and pressure-test connector pre-dive. Nylon shoulder bushings at the M4 flange mount isolate servo power-return from the ROV frame, preventing stray return current through seawater (`ELECTRICAL.md §5`). |
| **Graceful degradation** | Lose that actuator axis. Connector-level short isolated from ROV bus by in-line fuse and frame isolation — other gripper axis and ROV subsystems unaffected if isolation is intact. Abort dive for connector inspection. |

### M6 — Gear tooth wear and fatigue over cycles

| Field | Detail |
|---|---|
| **Cause** | Cyclic bending at the crown/pinion interface; PA12-GF accumulates fatigue damage under current-limited load; micro-abrasion in seawater-lubricated contact (seawater is a poor tribological fluid); any overload event accelerates crack initiation at the tooth root. |
| **Detection** | Growing backlash measured as position hysteresis on a close/open cycle; `present_position` drift under constant `goal_current`; visible tooth deformation on post-dive inspection. |
| **Mitigation** | PA12-GF material for higher fatigue life vs plain PA12 (`DRIVETRAIN.md §2`). Current-limit held strictly at or below T_safe — operating margin preserved over the teeth. Post-dive visual and functional inspection (backlash check). Log cycle count; replace printed gear set at an interval established empirically by `BENCH_TEST.md`. |
| **Graceful degradation** | Increasing backlash degrades position repeatability before catastrophic tooth loss — progressive failure, not sudden. Early warning is available from telemetry drift before complete failure. Printed gear set is a low-cost replaceable part: by design, a consumable. |

---

## Sensing failure modes — the pivot's new failure surface

The sensing pivot — motor current as grip-force sensor — is the design's
key capability and its primary new failure surface. Removing fingertip
electronics eliminates one underwater failure surface (wet wiring, connectors,
electrolysis) but concentrates force-sensing reliability in the RS-485
telemetry chain and the calibration model. The modes below cover that chain
specifically. These are the failure modes that did **not** exist in a
conventional position-only gripper.

### S1 — Telemetry dropout: RS-485 packet loss or bus noise

| Field | Detail |
|---|---|
| **Cause** | Thruster PWM and switching regulators couple common-mode noise into an unshielded RS-485 run; long tether (> 20 m) with reflections at baud > 1 Mbaud; missing or mismatched 120 Ω termination resistors; bus collision from servo addressing error. |
| **Detection** | CRC-fail or absent reply packets at the topside parser (`COMM_RX_TIMEOUT`, `COMM_RX_CORRUPT` in the DYNAMIXEL SDK); packet loss rate > 1 %; watchdog timer fires on reply absence > 100 ms. |
| **Mitigation** | Shielded twisted-pair (STP) for D+/D− in the tether. 120 Ω termination resistors at both ends of the RS-485 segment. Baud rate reduced to ≤ 1 Mbaud for tethers > 20 m (`ELECTRICAL.md §4c`). Retry logic in the topside parser (≥ 3 retries before fault declaration). Watchdog with escalating response: retry → fallback → abort. |
| **Graceful degradation** | **Fall back to open-loop position control** — no force feedback. Gripper closes to a pre-defined position target with a conservative fixed current limit. Grip is safe (the current ceiling still protects the gears and the specimen) but not adaptive. Operator is alerted; re-establish comms before resuming force-controlled operation. |

### S2 — Current-sense offset / gain drift

| Field | Detail |
|---|---|
| **Cause** | Servo internal current-sense ADC offset shifts with temperature or age; `K_t` varies ±5–10 % unit-to-unit per datasheet; friction model (`I_0` no-load current) changes with wear or lubrication state; shunt resistance drift in the servo's internal circuit. |
| **Detection** | Non-zero `present_current` at known no-load (motor enabled, no grip load applied); calibration check against a bench load cell returns error outside the ±0.3 N acceptance band (`SENSING.md §3`); two successive session-start calibration checks diverge by > 5 mA. |
| **Mitigation** | Periodic tare: zero `I_0` at no-load at the start of each dive session. Re-run the full current→force calibration curve (`SENSING.md §3`) after any servo replacement or significant thermal excursion. Log the `I_0` baseline; flag deviation > 5 mA session-to-session as a re-calibration trigger. |
| **Graceful degradation** | Force readout is biased by a fixed offset — reads systematically high or low. The force cap (current-limit register) is still hardware-enforced and unaffected by ADC drift. Widen the grip-force safety margin in the control setpoint until re-calibrated. |

### S3 — Calibration drift after thermal cycling

| Field | Detail |
|---|---|
| **Cause** | Motor winding `K_t` drifts ~−0.1 %/°C. Cold seawater (5–15 °C) shifts a bench calibration done at 20–25 °C by several percent. Servo self-heating during operation partially offsets cold immersion — the net is a non-stationary baseline. |
| **Detection** | Known-weight calibration check (`BENCH_TEST.md`) returns force error that grows with the temperature delta between calibration environment and deployment water temperature. Error grows approximately a few percent per 10 °C step. |
| **Mitigation** | Temperature-compensated calibration: record water temperature at calibration time and apply a `K_t(T)` correction factor. Re-run calibration after any > 10 °C environmental step. Use `present_temperature` from the servo's own internal thermistor as the real-time winding temperature proxy for a live correction term. |
| **Graceful degradation** | Force error grows with temperature delta. At 15 °C delta: ~1.5 % `K_t` error — a small fraction of a newton at the operating range. The current-limit gear ceiling is temperature-independent (it is a raw current count, not a force number) — mechanical protection is unaffected by thermal drift in `K_t`. |

### S4 — Sense saturation at stall: current pinned at the firmware limit

| Field | Detail |
|---|---|
| **Cause** | Object harder than expected; gripper hits a hard stop; current-limit fires and holds. `present_current` is pinned at `current_limit` — the ADC is at its commanded ceiling, not at a hardware rail. |
| **Detection** | `present_current` reads constant at or near `current_limit` for > 200 ms; `present_position` stops advancing; force estimate is stuck at the ceiling value with no dynamic information. |
| **Mitigation** | Design the normal working range to operate **below** the current-limit ceiling. The commanded grip force setpoint should run at 70–80 % of the limit so the force estimate retains headroom before saturation. The limit is a protective cap — it is not meant to be the operating point. |
| **Graceful degradation** | Above the ceiling, grip force is **"at least X N"** — a lower bound, not a precise number. This is the intended behaviour: the limit IS the mechanical protection ceiling. Safe recovery: back off the position command to reduce current; re-engage with a lower setpoint. Do not treat saturation as a sensor fault — it is the gear-protection mechanism functioning correctly. |

### S5 — Loss of force feedback in servo fault or overtemperature state

| Field | Detail |
|---|---|
| **Cause** | Sustained high-current operation without duty cycling; sealed canister blocking convection; ambient water temperature higher than expected; repeated stall events without cooling intervals. The servo's own protection trips an overtemperature shutdown (XW540 hardware error register, overheating bit). |
| **Detection** | `present_temperature` approaches or exceeds the servo protection threshold (~80 °C internal for XW540); servo error register (reg 70) sets the overheating bit; torque is disabled by the servo's own protection firmware; RS-485 comms remain active while torque is off — the fault is readable. |
| **Mitigation** | Monitor `present_temperature` continuously at every telemetry poll. Alarm and reduce duty cycle at a conservative threshold (e.g. 65 °C — 15 °C headroom before servo self-trip). Design the grip-and-hold duty cycle with the thermal budget in mind. Flooded gripper body conducts heat from the servo body into seawater — a real thermal management advantage of the flooded design vs. a sealed-air enclosure. |
| **Graceful degradation** | Servo disables its own torque. **Force feedback is lost** — current is no longer a valid force proxy when torque is off. Fall back to position-only control with conservative open-loop targets. Abort the current grasp; allow cooling before re-engaging. Log overtemperature events — repeated occurrence indicates a duty-cycle or thermal design violation. |

---

## Prioritisation

**Highest likelihood × highest severity (address first):**

1. **M1 — Gear tooth yield under stall.** Likelihood: High (both servos exceed
   T_safe by 10–280× without a limit). Severity: 5 (loss of gripper mechanism,
   no field repair). Mitigation is a firmware register write — it costs nothing,
   but must be re-verified after every flash.

2. **S1 — Telemetry dropout.** Likelihood: Medium-High (thruster noise + long
   tether is a realistic ROV environment). Severity: 4 (loss of force feedback;
   fall to open-loop). Termination resistors and shielded cable are cheap
   insurance; the open-loop fallback keeps the system safe but uncontrolled.

3. **M2 / M5 — Water ingress (servo body or connector).** Likelihood: Medium
   (IP68 servo body is robust; connectors and canisters are the weak points in a
   flooded-body design). Severity: 4–5 (loss of actuator axis; possible ROV bus
   fault if isolation fails). Pre-dive protocol and connector tier selection are
   the primary controls.

4. **S3 / S2 — Calibration drift (thermal or offset).** Likelihood: Medium
   (unavoidable in the field). Severity: 2–3 (force readout error; mechanical
   protection is intact). The current-limit ceiling is a raw current count — it
   is immune to `K_t` drift. Force accuracy degrades, gear protection does not.
   Manageable with a session-start tare and temperature-compensated calibration.

5. **M3 — Brown-out / power loss.** Likelihood: Low-Medium (proper sizing
   prevents it; shared ROV supply is unpredictable). Severity: 3 (dropped
   object; no hardware damage). See key safety statement below.

6. **S4 — Saturation at the current limit.** Likelihood: Low (operating point
   is designed below the ceiling). Severity: 1 (expected, designed behaviour —
   not a fault). Clearly document so operators do not misread the saturated
   readout as a sensor failure.

**Lower priority** (by design, already bounded):

- **M4** back-drive overload: chain back-driveability is a feature; magnetic-pod
  pole-slip is a built-in clutch that caps the overload torque.
- **M6** wear/fatigue: printed gear set is a consumable; replace on a cycle
  schedule once `BENCH_TEST.md` establishes the empirical interval.
- **S5** overtemperature: seawater cooling is a design advantage; duty-cycle
  discipline prevents the condition.

---

## Key safety statement

> **The drivetrain is back-drivable.** There is no worm gear, brake, or
> self-locking stage. A powered positional servo holds actively; an unpowered
> chain is mechanically free to back-drive to the open position. **On any power
> loss — brown-out, fuse blow, tether fault, servo reboot — the gripper opens
> and the held object is released.** This is the intended safe state: it
> prevents a stuck-closed failure during a loss-of-power event and protects
> specimen and mechanism from a dead-stick grip. If mission requirements demand
> hold-through-power-loss (e.g. sample retention during an emergency ROV ascent),
> a self-locking stage or mechanical brake must be explicitly added — accepting
> that it removes the back-drive overload escape (M4) and changes the M3
> brown-out behaviour from "releases" to "holds until manually opened." That
> trade is a mission-design decision, not a default of the current architecture.

---

> **Analysis status.** All failure modes, mitigations, and degradation paths
> are pre-deployment analytical assessments derived from datasheets, computed
> FEA estimates, and design documents. No failure modes have been exercised on
> built hardware. `BENCH_TEST.md` is the empirical validation plan. Numbers in
> this document (T_safe, current limits, temperature thresholds, force errors)
> inherit the honesty caveats of `DRIVETRAIN.md §7`, `SENSING.md §6`, and
> `ELECTRICAL.md §6c`.

Cross-links: `DRIVETRAIN.md` · `SENSING.md` · `ELECTRICAL.md` · `BENCH_TEST.md` · `../docs/UNDERWATER.md`

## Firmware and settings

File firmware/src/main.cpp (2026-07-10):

// Gripper controller firmware — Waveshare General Driver for Robots (ESP32-WROOM-32).
//
// Boots into a Wi-Fi access point, serves a mobile OPEN/CLOSE/calibrate web UI,
// and drives a Feetech STS bus servo (STS3250 / STS3215) plugged straight into
// the board's ST3215 bus port. Fully offline — no internet, no router.
//
//   Wi-Fi:  SSID "Gripper" / pass "gripper1234"  ->  http://192.168.4.1/
//   Servo:  Serial1 on GPIO18 (RXD) / GPIO19 (TXD), 1,000,000 baud, ID 1
//
// Power the board from ~12 V (3S) so the bus feeds the 12 V STS3250 correctly,
// and check the 3-pin connector orientation before powering up.

#include <Arduino.h>
#include <WiFi.h>
#include <WebServer.h>
#include <DNSServer.h>
#include <Preferences.h>
#include <Wire.h>
#include <SCServo.h>
#include "index_html.h"

// ---- compile-time options ---------------------------------------------------
#define USE_OLED 1          // 0.91" SSD1306 on the board (set 0 to drop the dep)

// ---- board pin map (Waveshare General Driver for Robots) ---------------------
static const int S_RXD = 18;     // bus servo UART RX
static const int S_TXD = 19;     // bus servo UART TX
static const int I2C_SDA = 32;   // OLED / IMU / INA219
static const int I2C_SCL = 33;

// ---- appliance config -------------------------------------------------------
static const char *AP_SSID = "Gripper";
static const char *AP_PASS = "gripper1234";   // WPA2 needs >= 8 chars
static const uint8_t SERVO_ID = 1;            // Feetech factory default
static const uint32_t SERVO_BAUD = 1000000;
static const IPAddress AP_IP(192, 168, 4, 1);

// ---- globals ----------------------------------------------------------------
SMS_STS st;
WebServer server(80);
DNSServer dns;
Preferences prefs;

int openPos = 1024;     // placeholders — calibrate via the UI
int closePos = 3072;
int moveSpeed = 1500;   // steps/s
int moveAcc = 50;

// stop-on-load (measured on this gripper: free-motion load caps ~300, so 350
// clears it; free motion never reaches it, so a short hold suffices)
bool stopOnLoad = false;
int loadLimit = 350;    // load magnitude (0-1023) above free-motion that = contact
int loadHoldMs = 150;   // load must stay over the limit this long (sustained window)

#if USE_OLED
#include <Adafruit_GFX.h>
#include <Adafruit_SSD1306.h>
Adafruit_SSD1306 oled(128, 32, &Wire, -1);
bool hasOled = false;
#endif

// ---- config persistence (NVS) ----------------------------------------------
void loadCfg() {
  prefs.begin("gripper", true);
  openPos = prefs.getInt("open", openPos);
  closePos = prefs.getInt("close", closePos);
  moveSpeed = prefs.getInt("speed", moveSpeed);
  moveAcc = prefs.getInt("acc", moveAcc);
  stopOnLoad = prefs.getBool("sol", stopOnLoad);
  loadLimit = prefs.getInt("llim", loadLimit);
  loadHoldMs = prefs.getInt("lhold", loadHoldMs);
  prefs.end();
}
void saveCfg() {
  prefs.begin("gripper", false);
  prefs.putInt("open", openPos);
  prefs.putInt("close", closePos);
  prefs.putInt("speed", moveSpeed);
  prefs.putInt("acc", moveAcc);
  prefs.putBool("sol", stopOnLoad);
  prefs.putInt("llim", loadLimit);
  prefs.putInt("lhold", loadHoldMs);
  prefs.end();
}

// ---- servo ------------------------------------------------------------------
void moveTo(int pos) {
  pos = constrain(pos, 0, 4095);
  st.EnableTorque(SERVO_ID, 1);
  st.WritePosEx(SERVO_ID, pos, moveSpeed, moveAcc);
}

// Present-load magnitude (0-1023) from the cached FeedBack, robust to whether
// the lib hands back a signed value or the raw sign-magnitude word (bit 0x400 =
// direction). Returns -1 if the feedback read failed.
static int loadMag(int fb) {
  if (fb == -1) return -1;
  int raw = st.ReadLoad(-1);
  return (raw < 0 ? -raw : raw) & 0x3FF;
}

// Brake and hold wherever it is right now.
void stopHold() {
  int p = st.ReadPos(SERVO_ID);
  if (p != -1) { st.EnableTorque(SERVO_ID, 1); st.WritePosEx(SERVO_ID, p, moveSpeed, moveAcc); }
}

// Move to target but stop as soon as the load stays over loadLimit *consistently*
// for ~loadHoldMs -- a sliding window needs ~70% of samples over the limit, so
// brief gear blips don't trip it but real contact does. Mirrors the Orange Pi
// Python guarded_move(). Blocks the loop for the move (<=TIMEOUT), which is fine.
String guardedMove(int target) {
  target = constrain(target, 0, 4095);
  st.EnableTorque(SERVO_ID, 1);
  st.WritePosEx(SERVO_ID, target, moveSpeed, moveAcc);

  const uint32_t GRACE = 180, POLL = 20, TIMEOUT = 5000;   // ms
  const int MAXW = 64;
  int window = (int)loadHoldMs / (int)POLL;
  if (window < 3) window = 3;
  if (window > MAXW) window = MAXW;
  int need = (int)(window * 0.7 + 0.5);
  if (need < 2) need = 2;

  bool buf[MAXW];
  int idx = 0, filled = 0, sum = 0;
  int lastPos = -1, lastMag = 0;
  uint32_t t0 = millis();
  delay(GRACE);                                   // ignore acceleration inrush
  while (millis() - t0 < TIMEOUT) {
    uint32_t ts = millis();
    int fb = st.FeedBack(SERVO_ID);
    int pos = (fb != -1) ? st.ReadPos(-1) : -1;
    int mag = loadMag(fb);
    if (pos != -1) lastPos = pos;
    if (mag >= 0) lastMag = mag;
    bool over = (mag >= 0) && (mag >= loadLimit);

    if (filled == window) sum -= buf[idx] ? 1 : 0; else filled++;
    buf[idx] = over; sum += over ? 1 : 0; idx = (idx + 1) % window;

    if (filled == window && sum >= need) {
      int hp = (lastPos != -1) ? lastPos : target;
      st.WritePosEx(SERVO_ID, hp, moveSpeed, moveAcc);      // brake + hold
      return String("{\"ok\":true,\"stopped\":true,\"reason\":\"load\",\"position\":")
           + hp + ",\"load\":" + lastMag + ",\"target\":" + target + "}";
    }
    if (pos != -1 && abs(pos - target) <= 12)
      return String("{\"ok\":true,\"stopped\":false,\"reason\":\"reached\",\"position\":")
           + pos + ",\"target\":" + target + "}";

    uint32_t el = millis() - ts;
    if (el < POLL) delay(POLL - el);
  }
  return String("{\"ok\":true,\"stopped\":false,\"reason\":\"timeout\",\"position\":")
       + lastPos + ",\"target\":" + target + "}";
}

// Route a move through the guard when stop-on-load is enabled, else a plain move.
String doMove(int target) {
  if (stopOnLoad) return guardedMove(target);
  moveTo(target);
  return String("{\"ok\":true,\"target\":") + constrain(target, 0, 4095) + "}";
}

String statusJson() {
  String j = "{";
  int fb = st.FeedBack(SERVO_ID);          // one bus round-trip; cache the rest
  bool online = (fb != -1);
  j += "\"connected\":";
  j += online ? "true" : "false";
  if (online) {
    j += ",\"position\":" + String(st.ReadPos(-1));
    j += ",\"load\":" + String(st.ReadLoad(-1));
    j += ",\"voltage\":" + String(st.ReadVoltage(-1) / 10.0, 1);
    j += ",\"temp\":" + String(st.ReadTemper(-1));
  } else {
    j += ",\"position\":null,\"load\":null,\"voltage\":0,\"temp\":null";
  }
  j += ",\"open_pos\":" + String(openPos);
  j += ",\"close_pos\":" + String(closePos);
  j += ",\"speed\":" + String(moveSpeed);
  j += ",\"acc\":" + String(moveAcc);
  j += ",\"stop_on_load\":"; j += stopOnLoad ? "true" : "false";
  j += ",\"load_limit\":" + String(loadLimit);
  j += ",\"load_hold_ms\":" + String(loadHoldMs);
  j += "}";
  return j;
}

// ---- HTTP handlers ----------------------------------------------------------
void sendJson(const String &body, int code = 200) {
  server.sendHeader("Access-Control-Allow-Origin", "*");   // let a localhost gamepad page talk to us
  server.send(code, "application/json", body);
}
void servePage() {
  server.sendHeader("Access-Control-Allow-Origin", "*");
  server.send_P(200, "text/html", INDEX_HTML);
}

void handleStatus() { sendJson(statusJson()); }
void handleOpen() { sendJson(doMove(openPos)); }
void handleClose() { sendJson(doMove(closePos)); }

void handleGoto() {
  if (!server.hasArg("pos")) return sendJson("{\"error\":\"pos required\"}", 400);
  int p = server.arg("pos").toInt();
  sendJson(doMove(p));
}

// Raw, always-unguarded move -- for live/streamed control (e.g. a gamepad trigger)
// where blocking on stop-on-load would stall the stream. Returns immediately.
void handleJog() {
  if (!server.hasArg("pos")) return sendJson("{\"error\":\"pos required\"}", 400);
  moveTo(server.arg("pos").toInt());
  sendJson("{\"ok\":true}");
}

void handleTorque() {
  String v = server.arg("on");
  bool on = !(v == "0" || v == "false" || v == "off");
  st.EnableTorque(SERVO_ID, on ? 1 : 0);
  sendJson(String("{\"ok\":true,\"torque\":") + (on ? "true" : "false") + "}");
}

void handleStopOnLoad() {
  String v = server.arg("on");
  stopOnLoad = !(v == "0" || v == "false" || v == "off");
  saveCfg();
  sendJson(String("{\"ok\":true,\"stop_on_load\":") + (stopOnLoad ? "true" : "false") + "}");
}

void handleStop() { stopHold(); sendJson("{\"ok\":true}"); }

void handleCalibrate() {
  String which = server.arg("which");
  if (which != "open" && which != "close")
    return sendJson("{\"error\":\"which=open|close\"}", 400);
  int p = st.ReadPos(SERVO_ID);
  if (p == -1) return sendJson("{\"error\":\"servo not connected\"}", 503);
  if (which == "open") openPos = p; else closePos = p;
  saveCfg();
  sendJson("{\"ok\":true,\"" + which + "_pos\":" + String(p) + "}");
}

void handleConfig() {
  if (server.hasArg("open")) openPos = constrain(server.arg("open").toInt(), 0, 4095);
  if (server.hasArg("close")) closePos = constrain(server.arg("close").toInt(), 0, 4095);
  if (server.hasArg("speed")) moveSpeed = max(0, (int)server.arg("speed").toInt());
  if (server.hasArg("acc")) moveAcc = constrain(server.arg("acc").toInt(), 0, 255);
  if (server.hasArg("load_limit")) loadLimit = constrain(server.arg("load_limit").toInt(), 0, 1023);
  if (server.hasArg("load_hold_ms")) loadHoldMs = constrain(server.arg("load_hold_ms").toInt(), 20, 1280);
  saveCfg();
  sendJson(statusJson());
}

// ---- OLED -------------------------------------------------------------------
#if USE_OLED
void drawOled() {
  if (!hasOled) return;
  int pos = st.ReadPos(SERVO_ID);
  oled.clearDisplay();
  oled.setTextColor(SSD1306_WHITE);
  oled.setTextSize(1);
  oled.setCursor(0, 0);  oled.print("GRIPPER  AP");
  oled.setCursor(0, 10); oled.print(AP_SSID); oled.print("/"); oled.print(AP_PASS);
  oled.setCursor(0, 20);
  oled.print("192.168.4.1  ");
  if (pos == -1) oled.print("--"); else oled.print(pos);
  oled.display();
}
#endif

// ---- setup / loop -----------------------------------------------------------
void setup() {
  Serial.begin(115200);
  loadCfg();

  // bus servo
  Serial1.begin(SERVO_BAUD, SERIAL_8N1, S_RXD, S_TXD);
  st.pSerial = &Serial1;

#if USE_OLED
  Wire.begin(I2C_SDA, I2C_SCL);
  hasOled = oled.begin(SSD1306_SWITCHCAPVCC, 0x3C);
  if (hasOled) { oled.clearDisplay(); oled.display(); }
#endif

  // access point
  WiFi.mode(WIFI_AP);
  WiFi.softAPConfig(AP_IP, AP_IP, IPAddress(255, 255, 255, 0));
  WiFi.softAP(AP_SSID, AP_PASS);
  dns.start(53, "*", AP_IP);             // captive-portal: all names -> us

  // routes (each handles any method; UI uses POST for actions, GET for status)
  server.on("/", servePage);
  server.on("/api/status", handleStatus);
  server.on("/api/open", handleOpen);
  server.on("/api/close", handleClose);
  server.on("/api/goto", handleGoto);
  server.on("/api/jog", handleJog);
  server.on("/api/torque", handleTorque);
  server.on("/api/stop_on_load", handleStopOnLoad);
  server.on("/api/stop", handleStop);
  server.on("/api/calibrate", handleCalibrate);
  server.on("/api/config", handleConfig);
  server.onNotFound(servePage);          // captive-portal probes land on the UI
  server.begin();

  Serial.printf("Gripper AP '%s' up at %s\n", AP_SSID, AP_IP.toString().c_str());
}

void loop() {
  dns.processNextRequest();
  server.handleClient();

#if USE_OLED
  static uint32_t lastOled = 0;
  if (millis() - lastOled > 1000) { lastOled = millis(); drawOled(); }
#endif
}

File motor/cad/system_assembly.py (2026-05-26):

"""
system_assembly.py — the FULL gripper-plus-canister-plus-actuator
integrated assembly. Brings every bought + printed + existing-gripper
part into one Compound, in world coordinates.

Two variants, mirroring `motor/ROV_INTEGRATION.md` §2d:

    T2 (primary, ≤30 m): Option A — Ø8 stainless shaft through Ø14 lip seal
                          in a blank BR end cap. Worked example: STS3250.
    T3 (fallback, >30 m): Option B — magnetic coupling; no shaft penetrates
                          the canister wall. Inner & outer N52 rotors with
                          a thin printed barrier.

Note on bracketry (per advisor):
    The gripper has a 4 × M4 bolt pattern on its base flange sized for the
    ROV arm. The Blue Robotics 3" end cap has a 6 × M3 perimeter pattern
    around its flange. These do NOT mate directly; in service both the
    gripper and the canister are independently fixed to the ROV arm with
    user-supplied arm-side bracketry, and the shaft is the only mechanical
    link between them. Here we position them coaxially with a small air
    gap and leave the bracketry as a user-supplied item.

Coordinate frame (matches gripper.py final world frame, +90X reoriented):
    +X horizontal, +Z up (fingers point up), gripper flange face at z=-25,
    shaft / canister axis along world Z, centred on (DRIVE_X, -DRIVE_Z)
    = (-12, -11.72).

Run from repo root:
    python motor/cad/system_assembly.py             # T2 variant (default)
    GRIPPER_CANISTER_VARIANT=T3 python motor/cad/system_assembly.py
Outputs to motor/cad/output/.
"""

from __future__ import annotations

import os
import sys

# import gripper.py from the repo root
sys.path.insert(0, os.path.abspath(os.path.join(os.path.dirname(__file__), "..", "..")))
sys.path.insert(0, os.path.dirname(__file__))

import math

from build123d import (
    Box,
    Color,
    Compound,
    Cylinder,
    Location,
    Plane,
    export_step,
)

# Existing gripper:
import gripper as G

# Purchased + printed parts (this folder)
from external_parts import (
    dynamixel_xw540,
    feetech_sts3250,
    feetech_sts3215,
    dynamixel_xm540,
    br_tube_3in_240,
    br_tube_3in_150,
    br_end_cap_wet_lipseal,
    br_end_cap_dry_4xm10,
    wetlink_penetrator,
    wetlink_blank_m10,
    lip_seal_8x14x4,
    gobilda_shaft_8x50,
    n52_magnet_ring_80mm,
    ktr_minex_sa_60_8,
    TUBE_LEN_240,
    TUBE_LEN_150,
    CAP_FLANGE_T,
    CAP_BOSS_LEN,
    CAP_TOTAL_LEN,
    TUBE_ID_3IN_ACR,
)
from printed_adapters import (
    servo_horn_adapter,
    wet_d_socket,
    servo_cradle,
    cradle_endcap_spacer,
    wrist_plate,
    canister_fairing,
    pod_cap_shroud,
    gripper_taper_cover,
    WRIST_PLATE_H,
    CANISTER_FAIRING_OD,
    POD_CAP_T,
    GRIPPER_TAPER_COVER_H,
)

VARIANT = os.environ.get("GRIPPER_CANISTER_VARIANT", "T2").upper()
SERVO   = os.environ.get("GRIPPER_CANISTER_SERVO", "STS3250").upper()
OUT_DIR = os.path.join(os.path.dirname(__file__), "output")

# --------------------------------------------------------------------------
# World-frame anchors (post the gripper's +90X reorient)
# --------------------------------------------------------------------------
# Gripper input D-coupler exits the flange bottom face at:
SHAFT_X_W = G.DRIVE_X                              # -12 (off-centre by design — the
                                                   # gripper drives off the left gear pivot)
SHAFT_Y_W = -G.DRIVE_Z                             # -11.72
FLANGE_BOT_Z = G.BOT_FLANGE_Y[0]                   # -25 (flange bottom face)
GRIPPER_COUPLER_BOT_Z = (G.BOT_FLANGE_Y[0]
                         - G.SHAFT_SHOULDER_T
                         - G.SHAFT_COUPLER_LEN)    # -25 - 2 - 12 = -39

# Canister body is CENTRED on the gripper enclosure CENTROID. The gripper
# enclosure spans model ENC_X (-48..48) × ENC_Z (0..24), so its centroid in
# world frame (after the gripper's +90X reorient: model+Y→world+Z, model+Z→world-Y)
# is at world (X=0, Y=-12). The SHAFT is off-centre at (X=-12, Y≈-12) — so
# Y is essentially aligned with the enclosure but X is offset by 12 mm.
CANISTER_X_W = 0.0                                 # gripper enclosure ENC_X centroid
CANISTER_Y_W = -12.0                               # gripper enclosure ENC_Z centroid (= 12) → world -Y
SHAFT_OFFSET_X = SHAFT_X_W - CANISTER_X_W          # -12 — shaft offset from canister axis
SHAFT_OFFSET_Y = SHAFT_Y_W - CANISTER_Y_W          # ~+0.3 — essentially zero (shaft Y nearly = canister Y)

# Canister hangs below the gripper. We leave a small air gap between the
# bottom of the gripper coupler and the top of the wet D-socket: the D-socket
# is what RECEIVES that coupler, so they overlap, not abut.
#
# The wet D-socket's TOP is the gripper-coupler-engagement face; it must
# sit at z = FLANGE_BOT_Z so the gripper coupler (which extends from
# z=FLANGE_BOT_Z-2 down to FLANGE_BOT_Z-14) engages by 12 mm of the
# socket's 20 mm height. So:
WET_DSOCKET_TOP_Z = FLANGE_BOT_Z - 2.0             # leave 2 mm air-gap to flange face
WET_DSOCKET_LEN = 20.0
WET_DSOCKET_BOT_Z = WET_DSOCKET_TOP_Z - WET_DSOCKET_LEN

# The shaft press-fits into the bottom of the wet D-socket 6 mm. Its top
# end is therefore 6 mm below the socket top; shaft hangs down from there
# for 50 mm. The lip seal sits ON the shaft mid-length, captured in the
# end cap.
SHAFT_TOP_Z = WET_DSOCKET_BOT_Z + 6.0              # press-fit overlap
SHAFT_BOT_Z = SHAFT_TOP_Z - 50.0                   # 50 mm goBILDA shaft

# The wet end cap exterior (wet, +Z) face sits roughly midway down the
# shaft (so ~25 mm of shaft sits in the canister, ~25 mm carries the
# wet D-socket above the cap). With cap total length 23 mm, the cap
# spans:
WET_CAP_EXT_FACE_Z = SHAFT_TOP_Z - 22.0            # cap top face (wet side)
WET_CAP_INT_FACE_Z = WET_CAP_EXT_FACE_Z - CAP_TOTAL_LEN

# Tube butts against the cap's interior shoulder (flange ↔ boss step at
# z = WET_CAP_EXT_FACE_Z - CAP_FLANGE_T). Boss extends CAP_BOSS_LEN
# into the tube. Tube length 240 mm.
WET_CAP_FLANGE_BOT_Z = WET_CAP_EXT_FACE_Z - CAP_FLANGE_T
TUBE_TOP_Z = WET_CAP_FLANGE_BOT_Z                  # tube butts against flange
TUBE_BOT_Z = TUBE_TOP_Z - TUBE_LEN_240
TUBE_CENTRE_Z = (TUBE_TOP_Z + TUBE_BOT_Z) / 2.0

# Dry end cap is the mirror at the bottom.
DRY_CAP_FLANGE_TOP_Z = TUBE_BOT_Z
DRY_CAP_EXT_FACE_Z = DRY_CAP_FLANGE_TOP_Z - CAP_FLANGE_T   # cap bottom (dry, exterior)
DRY_CAP_INT_FACE_Z = DRY_CAP_FLANGE_TOP_Z + CAP_BOSS_LEN   # interior shoulder inside the tube

# Cradle + spacer sit on top of the dry cap interior.
SPACER_T = 4.0
SPACER_BOT_Z = DRY_CAP_INT_FACE_Z
SPACER_TOP_Z = SPACER_BOT_Z + SPACER_T
CRADLE_BOT_Z = SPACER_TOP_Z


def _move_to_canister_axis(part, z_centre):
    """Move a part whose local origin is on its symmetry axis (z = 0) to
    sit centred on the SHAFT axis (off-centre by 12 mm) — legacy T2 helper."""
    return part.moved(Location((SHAFT_X_W, SHAFT_Y_W, z_centre)))
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

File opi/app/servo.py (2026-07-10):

"""Minimal, self-contained Feetech STS/SMS serial-bus servo driver.

Targets the gripper actuator: Feetech STS3250 (also works with STS3215) on the
SCS-TTL half-duplex bus, driven through an FE-URT-1 (CH340) USB adapter at
1,000,000 baud. Pure Python on top of the vendored pyserial -- no external SDK,
so it runs on the offline Orange Pi with only the system Python 3.

Protocol (Feetech "SMS/STS" series, little-endian 16-bit values):
    packet = [0xFF, 0xFF, ID, LEN, INST, *PARAMS, CHECKSUM]
    LEN      = len(PARAMS) + 2
    CHECKSUM = ~(ID + LEN + INST + sum(PARAMS)) & 0xFF
"""

import os
import glob
import threading
import time
from collections import deque

import serial  # vendored in ./vendor

# --- SMS/STS RAM register map -------------------------------------------------
ADDR_TORQUE_ENABLE = 40
ADDR_ACC = 41
ADDR_GOAL_POSITION = 42
ADDR_GOAL_TIME = 44
ADDR_GOAL_SPEED = 46
ADDR_PRESENT_POSITION = 56
ADDR_PRESENT_SPEED = 58
ADDR_PRESENT_LOAD = 60
ADDR_PRESENT_VOLTAGE = 62
ADDR_PRESENT_TEMP = 63
ADDR_MOVING = 66
ADDR_PRESENT_CURRENT = 69

# --- instructions -------------------------------------------------------------
INST_PING = 0x01
INST_READ = 0x02
INST_WRITE = 0x03


def _decode_signed(value, sign_bit):
    """STS encodes some fields as magnitude + a direction bit (not two's comp)."""
    if value & sign_bit:
        return -(value & (sign_bit - 1))
    return value & (sign_bit - 1)


class Servo:
    """Thread-safe driver for a single Feetech STS servo on a shared bus.

    Resilient by design: if the adapter is unplugged the calls return None /
    False and the next call transparently tries to reopen the port, so the web
    UI keeps working with the servo physically absent.
    """

    def __init__(self, port="/dev/ttyUSB0", baud=1000000, servo_id=1, timeout=0.05):
        self.port = port
        self.baud = baud
        self.servo_id = servo_id
        self.timeout = timeout
        self._ser = None
        self._lock = threading.RLock()

    # -- connection ------------------------------------------------------------
    def _candidate_ports(self):
        order = []
        for p in (self.port, "/dev/feetech"):
            if p and p not in order:
                order.append(p)
        for p in sorted(glob.glob("/dev/ttyUSB*")) + sorted(glob.glob("/dev/ttyACM*")):
            if p not in order:
                order.append(p)
        return order

    def _ensure_open(self):
        if self._ser is not None and self._ser.is_open:
            return True
        for p in self._candidate_ports():
            if not os.path.exists(p):
                continue
            try:
                self._ser = serial.Serial(p, self.baud, timeout=self.timeout,
                                          write_timeout=0.2)
                self.port = p
                # let the CH340 settle
                time.sleep(0.05)
                self._ser.reset_input_buffer()
                return True
            except (serial.SerialException, OSError):
                self._ser = None
        return False

    def _close(self):
        try:
            if self._ser:
                self._ser.close()
        except Exception:
            pass
        self._ser = None

    @property
    def connected(self):
        with self._lock:
            return self.ping()

    # -- raw packet I/O --------------------------------------------------------
    def _send(self, inst, params):
        sid = self.servo_id
        length = len(params) + 2
        checksum = (~(sid + length + inst + sum(params))) & 0xFF
        pkt = bytes([0xFF, 0xFF, sid, length, inst, *params, checksum])
        self._ser.reset_input_buffer()
        self._ser.write(pkt)
        self._ser.flush()

    def _read_status(self, n_data):
        """Read a status packet, returning n_data payload bytes (or None)."""
        deadline = time.time() + 0.15
        buf = bytearray()
        want = 2 + 1 + 1 + 1 + n_data + 1  # FF FF ID LEN ERR data... CHK
        while time.time() < deadline:
            chunk = self._ser.read(want - len(buf) if want > len(buf) else 1)
            if chunk:
                buf.extend(chunk)
            # find a frame header (skip any half-duplex echo)
            i = buf.find(b"\xff\xff")
            if i >= 0 and len(buf) - i >= want:
                frame = buf[i:i + want]
                if frame[2] != self.servo_id:
                    del buf[:i + 2]
                    continue
                data = frame[5:5 + n_data]
                return bytes(data)
        return None

    # -- register access -------------------------------------------------------
    def write_reg(self, addr, data):
        with self._lock:
            if not self._ensure_open():
                return False
            try:
                self._send(INST_WRITE, [addr, *data])
                return True
            except (serial.SerialException, OSError):
                self._close()
                return False

    def read_reg(self, addr, length):
        with self._lock:
            if not self._ensure_open():
                return None
            try:
                self._send(INST_READ, [addr, length])
                return self._read_status(length)
            except (serial.SerialException, OSError):
                self._close()
                return None

    def _read_u16(self, addr):
        d = self.read_reg(addr, 2)
        if not d or len(d) < 2:
            return None
        return d[0] | (d[1] << 8)  # little-endian (STS series)

    # -- high-level API --------------------------------------------------------
    def ping(self):
        with self._lock:
            if not self._ensure_open():
                return False
            try:
                self._send(INST_PING, [])
                return self._read_status(0) is not None
            except (serial.SerialException, OSError):
                self._close()
                return False

    def torque(self, on):
        return self.write_reg(ADDR_TORQUE_ENABLE, [1 if on else 0])

    def move(self, position, speed=1500, acc=50):
        """Move to an absolute position (0-4095) with the given speed/acc.

        Writes ACC, GOAL_POSITION, GOAL_TIME(=0), GOAL_SPEED in one frame
        starting at ADDR_ACC (Feetech "WritePosEx").
        """
        position = max(0, min(4095, int(position)))
        speed = max(0, min(0x7FFF, int(speed)))
        acc = max(0, min(255, int(acc)))
        with self._lock:
            self.torque(True)
            params = [
                acc,
                position & 0xFF, (position >> 8) & 0xFF,
                0, 0,                                   # goal time
                speed & 0xFF, (speed >> 8) & 0xFF,
            ]
            return self.write_reg(ADDR_ACC, params)

    def present_position(self):
        v = self._read_u16(ADDR_PRESENT_POSITION)
        return None if v is None else (v & 0x7FFF)
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

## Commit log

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2026-05-23 feat: Fin Ray TPU fingers + enclosed housing, restyled
    - Replace rigid serrated jaws with Fin Ray-style compliant fingers (TPU):
    triangular truss of same-direction slanted ribs that wraps around objects
    - Enclose the gears/pivots/lower links in a clean hollow housing; links and
    fingers emerge through two top slots; drive shaft exits a back-wall bore
    - Back mounting flange (4x M4); fixed pivots hidden as internal axles
    - Restyle: dark-slate body, matte-black TPU jaws, steel internals
    - Same verified single-shaft four-bar drive; interactive sidecar re-verified
    - CCW-robust _poly_solid for mirrored boolean parts
    [gripper_closed.step, gripper_interactive.step, gripper_mid.step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]
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2026-05-23 feat: underwater adaptation + grip texture + fix arm clipping
    - Fix arms clipping the case: widen top slots to the measured link sweep
    (x[2.5,41] / mirror), lower+thin the top wall
    - Underwater: drain/flood holes (bottom row + low side holes) so the housing
    floods and drains, no trapped air; UNDERWATER.md engineering guide added
    (gears-underwater answer, flooded vs sealed, material BOM, sealing, checklist)
    - Grip texture: friction ridges on the Fin Ray contact faces (anti-slip),
    closed-pose gap kept positive (~0.8mm)
    - Regenerate poses, heroes, motion GIF; sidecar re-verified (mapping unchanged)
    - Built with parallel agents (texture, enclosure, underwater guide)
    [gripper_closed.step, gripper_interactive.step, gripper_mid.step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]
2026-05-23 fix: fuse gear+crank into drive arm, integral rear shaft, no clips, Z-up
    - Fuse gear sector + crank into one drive_arm per side -> removes gear/crank
    interpenetration (the reported clip)
    - LEFT drive arm has the integral input shaft + rear D-coupler exiting the
    back; removes the shaft-vs-gear clip and gives a real servo coupling
    - Trim each Fin Ray finger to its own half of the centreline -> fingers never
    collide at the closed pose (interference check clean across full travel)
    - Reorient assembly Z-up (fingers +Z, shaft out the back horizontally) for
    correct printing & viewing; sidecar rewritten for the Y hinge axis + new ids
    - Add PRINT_CLEAR clearance to axle bores
    - Programmatic i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
    [gripper_closed.step, gripper_interactive.step, gripper_mid.step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]
2026-05-23 feat: production-ready pass — assembleable housing, exports, full docs
    - Split housing into open-front body + bolt-on front_cover (4x M3); add
    captured-axle bosses (A_R/B_R/B_L), shaft bushing seat at A_L, corner screw
    columns -> the mechanism can actually be assembled and the axles supported
    both ends; full axle pins span back boss -> cover boss
    - Interference check CLEAN across travel with the cover in place
    - export_parts.py: per-part STEP+STL + parts/MANIFEST.md (8 printable parts;
    pins flagged as bought stainless hardware)
    - Docs: BOM.md, ASSEMBLY.md, PRINTING.md, UNDERWATER.md (materials, hardware,
    assembly order, print settings, flooded-underwater guidance)
    - Sidecar mappi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
    [drive_arm_L.step, drive_arm_L.stl, drive_arm_R.step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]
2026-05-23 feat: fully 3D-printable, zero-hardware design (snap pins, snap cover, print-friendly fingers)
    - Fingers: print-friendly fillets on rib-cell corners (TPU stress relief),
    base chamfer (elephant-foot), rounded tooth tips + blade apex; robust
    per-edge _safe_round so booleans never abort
    - Pins: replace all metal pivots with printed push-to-snap pins (flange head +
    split barbed tip that locks past the far face) -> tool-free, zero hardware
    - Cover: replace 4 M3 screws with 4 integral cantilever snap clips latching
    into side-wall windows -> tool-free
    - Interference CLEAN across travel; sidecar mapping unchanged (snap features
    fuse into existing parts)
    - Built with parallel agent swarm (f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
    [dev_snapcover_assembled.step, dev_snapcover_exploded.step, dev_snapcover_fullgripper.step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]
2026-05-23 fix: axle pins -> cover-trapped dowels, widen axle bores; docs+exports for all-printed
    - Axle pivots become plain headed dowels (snap_pin barb=False) captured between
    back-wall socket and cover boss; widen AXLE_SCREW_R to shank clearance
    (fixes 1.7mm M3-leftover bore that blocked the 2.3mm snap-pin shank)
    - Finger pins keep self-locking barbs (exit into free space)
    - Interference CLEAN across travel; sidecar re-verified
    - export_parts.py: label-based dedup (fixes pin name collision), all parts
    printable incl snap_pin_axle x3 / snap_pin_finger x4 / front_cover
    - BOM/ASSEMBLY/PRINTING rewritten for zero-hardware tool-free build
    - Regenerate poses, heroes, motion GIF, per-part STLs
    [drive_arm_L.step, drive_arm_R.step, enclosure.step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]
2026-05-23 feat: DFM-standard print pass + adjustable finger scale factor
    - DFM: mating clearance to FDM-standard 0.3 mm/side (PRINT_CLEAR), all pin
    bores routed through it; 0.4 mm edge-break chamfer (DFM_EDGE) on link bars.
    - Finger scale: GRIPPER_FINGER_SCALE env (0.6-2.5) scales blade len/width/tip
    only; mount holes, C/D spacing, walls, grip teeth, clearances stay fixed so
    any size still fits the linkage. Verified CLEAN at 0.7x and 1.6x.
    - DFM.md standards+compliance doc; README updated for both env vars.
    - Regenerated poses, interactive, per-part STL/STEP, heroes, motion GIF.
    [dev_snapcover_assembled.step, dev_snapcover_exploded.step, dev_snapcover_fullgripper.step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]
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2026-05-23 fix(dfm): 2mm axle-boss walls, snap-pin head edge-break; review fixups
    - BOSS_OD_R = AXLE_SCREW_R + 2.0 -> restores >=2mm wall around the axle bores
    on enclosure + cover (the widened 2.6mm bore had left only 0.9mm, violating
    the >=1.5mm functional-wall rule stated in DFM.md). Interference re-verified
    CLEAN at all poses.
    - snap_pin: 0.4mm chamfer on the head-flange rim (handled on insertion); barb
    catch face and gear-tooth flanks left deliberately crisp (functional).
    - DFM.md: document boss/bushing walls and the crisp-by-design surfaces.
    - Sidecar re-verified driving the corrected geometry at open=1.0.
    - Regenerated poses, interactive, STL/STEP, heroes, motion GIF.
    [drive_arm_L.step, drive_arm_R.step, enclosure.step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]
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2026-05-23 feat(production): geometric pin capture, vents, print plates — swarm audit fixes
    Swarm production-readiness audit (underwater durability + print-readiness +
    snap-fit engineering + assembly) and the resulting fixes:
    RETENTION (was the production-blocking FAIL): barbed finger pins relied on
    0.30mm of elastic preload -> creeps loose underwater. Now GEOMETRIC capture:
    - finger-pin lips snap into a rigid confined counterbore (radially constrains
    the lip so creep relaxes it OUTWARD; load bears on a solid shoulder),
    SNAP_BARB_SEAT 0.30->1.2mm, local eye boss for a solid pocket wall.
    - axle dowels sandwiched zero-slop between a back-bore step and the cover boss
    (fixed a prior 0.8mm interfer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
    [drive_arm_L.step, drive_arm_L.stl, drive_arm_R.step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]
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2026-05-23 fix(production): final material-aware review — 3 blocking fixes + PA12-GF/PETG-HF/TPU plan
    Final swarm review (materials, print-readiness, QA, code-review) against the
    pinned materials: PA12-GF body/arms/axle-dowels (PETG-HF for test prints),
    PETG-HF finger pins, TPU fingers. Three BLOCKING issues found and fixed:
    1. Closed-pose pin collision: at open=0 the finger-pin heads overlapped and a
    shank clipped the opposite arm (base_gap 7.55 < 2*head 7.80). THETA_CLOSED
    104->102 separates the C/D mount pins WITHOUT loosening grip (blade contact
    face is anchored to FR_CONTACT_OFFSET). Now CLEAN at open=0; gap 9.86mm.
    2. Cover-clip strain too high for brittle PA12-GF (3.2% > ~2% allowabl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
    [drive_arm_L.step, drive_arm_L.stl, drive_arm_R.step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]
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2026-05-23 fix: crown-pinion gear now genuinely meshes (was grazing/gapped)
    The right-angle input pinion was only grazing the crown teeth (4 mm^3, 1 mm tip
    dip into 1.6 mm teeth) -> looked like a gap, didn't drive. Deepened the mesh:
    CROWN_FACE_H 1.6->2.8 (taller face teeth), MESH_DEPTH 1.0->2.2 (pinion tips sit
    down in the crown valleys with flank contact). Now a real interleave:
    - static overlap ~16.5 mm^3 (teeth in valleys)
    - interleave proof: rotating the pinion +/-1/2 tooth swings overlap 0->16.5->124
    mm^3 (clears the gaps one way, collides the other) -- not a graze.
    Pitches match (2.09 mm). Kinematics byte-identical; full interference CLEAN at
    open 0/0.5/1.0; all 17 parts + 3 plates watertight.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
    [drive_arm_L.step, drive_arm_L.stl, drive_arm_R.step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]
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2026-05-24 chore: regenerate deliverables for slimmer clips + cover-rim fix
    Rebuild every derived artifact from gripper.py (poses, per-part STEP/STL, print
    plates, heroes, motion GIF) so they reflect the two source commits on this branch
    (slimmer snap-clip tabs + the cover-rim interference fix).
    All 3 print plates re-verified watertight; enclosure and front_cover watertight
    single-shell (front_cover volume 12353 -> 12153 mm^3, reflecting the thinner clip
    arms). No source changes in this commit.
    [drive_arm_L.step, drive_arm_R.step, enclosure.step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]
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2026-05-24 feat(finger): iter00 baseline FEA with corrected 2-bore clamp
    Realistic clamp (pin both bores C,D) exposes the real failure: engage 0.073,
    top-third force 0.00, apex flicks -11.8mm AWAY from object, margin 2.82x.
    Upper finger rotates rigidly about the pins instead of wrapping. Adds the
    design-iteration harness + process log.
    [section.step]
2026-05-24 feat(finger): Round 1 uniform-lever sweep (8 variants) — all negative
    No uniform parameter (wall, rib count, taper, tip cap, slant) moves the core
    metric: top-third force stays 0.00, contact band pinned at y~72-79, tip flicks
    away in every case. Contact-band invariance under all stiffness levers shows the
    finger rotates about the pins instead of the lattice conforming -> the fix must
    be structural, not a parameter tweak. Documented for the process record.
    [section.step]
2026-05-24 feat(finger): graded-wall params + closure-controlled FEA; slant & spine-gradient ruled out
    - gripper.py: directional/graded wall thickness (contact/spine/rib base->tip),
    None-default so byte-identical when unused (kinematics + section verified unchanged).
    - harness: report metrics at fixed 8mm closure (grip-controlled washed out at 5N).
    - Findings: reversed slant negative; spine-tip gradient DEAD (contact 22->22, no
    wrap). Away-bending cantilever mode dominates the Fin Ray curl. Next: stiff beams
    + thin ribs to decouple the modes.
    [section.step]
2026-05-24 feat(finger): stiff-beam/thin-rib decoupling DEAD — limit is geometric not material
    All ~14 stiffness variants fail to grow the contact patch (baseline has the most,
    22 nodes; every change reduces it). Visual confirms: finger below the contact
    curls toward the object (driven), but the free cantilever above has no driving
    load (vertical face tangent-touches the cylinder at one y) so it bends away.
    Fix must be geometric. Adds yc override to test object position.
    [section.step]
2026-05-24 feat(finger): position test + shorten test — geometric wall confirmed (17 runs)
    Object position (yc 80->95) doesn't help (contact 13, band tracks object).
    Shortening finger raises top-third metric to 1.0 but it's an artifact (band
    near short tip); tip still bends away, contact still a band, margin worse.
    Conclusion: this Fin Ray topology tangent-contacts a 44mm cylinder and the free
    portion above the contact bends away -- whole-finger wrap is a topology problem,
    not a parameter. gripper.py geometry kept at original (graded-wall params unused).
    [section.step]
2026-05-24 feat(finger): free-topology generator + scan — no Fin Ray topology wraps the apex
    Adds finray2.py (fully-parametric Fin Ray section: free beam angles, rib dir/angle,
    wall split) + harness hook + object R/yc overrides. Scan of fundamental topologies
    (default, reversed ribs, steep ribs, symmetric) all keep the apex bending AWAY
    (tip_inward ~-7, top-third 0). The away-bending of the free cantilever above the
    contact is structural, not a rib-scheme choice. Diagnostics next.
    [section.step]
2026-05-24 fix(fea): CORRECTION — apex-direction metric was wrong; the finger DOES wrap
    loadtest.py validation: even a textbook symmetric base-clamped Fin Ray has the
    apex move WITH the load (2 independent solvers agree) -> that is correct Fin Ray
    behaviour, not a bug. The wrap is the contact FACE conforming, not the apex
    curling toward. With the right metric (contact-patch growth with closure) the
    production finger wraps fine: contact grows 0->7->14->22->23 nodes with closure,
    ~20% stress spread. The 'top gets nothing' is geometric (finger tip is above the
    object) and largely unfixable, not a defect. Earlier variant rankings used the
    wrong metric.
    [section.step]
2026-05-24 feat(fea): wrap-quality metrics + renderer; optimization round 1
    Correct metrics now scored: contact arc around object + pressure evenness +
    margin. render_wrap.py: filled finger mesh (von Mises) conforming to the SOLID
    object, still + closing animation + side-by-side comparison. Round 1: contact
    arc only ~12deg (small patch); contact-wall gradient evens pressure (pcov
    0.74->0.53) for free; more ribs worse. Round 2 testing thinner contact beam.
    [section.step]
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2026-05-25 feat(finger): universal-adaptive Fin Ray finger (FEA across shapes & sizes)
    Redesign the finger for universal conformance instead of single-object tuning.
    Added a square-block object + size/height battery + force-targeted universal
    scorer to the FEA harness, and ran an agent-swarm search (~90 runs) over two
    finger families.
    - Flexure family ruled out: chaotic, uncontrollable grip force on round objects.
    - Winner (Fin Ray): thin compliant contact beam (1.2mm) + sharp tapered spine
    (tip 2mm) + 14 fine reversed-slant ribs (1.6mm). Universal score 0.65 vs 0.56.
    - Distributes pressure along the whole finger on flat/large objects, grips round
    ones safely and evenly across sizes (old finger pi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
    [drive_arm_L.step, drive_arm_R.step, enclosure.step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]
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2026-05-25 chore: regenerate all 3D deliverables for the new universal finger + doc fixes
    The committed assembly poses, hero renders and motion GIF still showed the
    PRE-redesign finger (last rebuilt before the universal-finger change). Re-run
    regen.sh to rebuild every derived artifact from gripper.py so they reflect the
    shipped finger: poses (closed/mid/open/interactive/scale16), per-part STEP/STL,
    print plates, hero PNGs, motion GIF.
    Also fix stale finger specs in the docs to the new walls (contact 1.2 / spine 1.8
    / rib 1.6 mm): DFM.md min-wall row (flags the intentionally-thin 1.2 mm contact
    beam, 3 solid perimeters), PRINTING.md direct-drive note + walls/infill table
    (now states the 100%-dense-wall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
    [drive_arm_L.step, drive_arm_R.step, enclosure.step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]
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2026-05-25 feat(drive): strengthen crown/pinion + gear FEA T_safe; keep ratio
    Phase-4 gear FEA (2D plane-stress, Lewis-checked) shows the printed crown/pinion is
    the gripper's structural limit. Ratio kept at 2.667:1 (STS3215 floor). Implemented +
    build-verified face-width strengthening (PINION_T 4->8, CROWN_TOOTH_H 1.6->3.0): no
    new interference, four-bar self-check unchanged, T_safe 0.02->0.034 N.m. Full
    module/radius re-size specified as a proposed option (DECISION_LOG D10-b). T_safe is
    the firmware current-limit ceiling (gear protection). Deliverables re-exported.
    [drive_arm_L.step, drive_arm_L.stl, drive_arm_R.step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]
2026-05-25 feat(motor): torque-chain + slip-margin + holding-stall sims, model + sensing
    Phase-5 closed-form sims (build on the exact kinematics): torque_chain (gear ceiling
    binds, not the servo), slip_margin (slimy worst class, rank-only, coupled to
    grip_model), holding_stall (back-drivable -> active hold, sub-amp; stall sets the bus
    budget). MOTOR_MODEL.md = forward+inverse (current->force) model, validation gates,
    +/-50% sensitivity (conclusions invariant). SENSING.md = the force-via-current sensor
    (calibration vs load cell, noise floor, honest limits).
    [_motor_sensitivity.json]
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2026-05-26 feat(motor/cad): centre canister on body + add tapering enclosure cover
    Refinements to the unibody visual:
    - Canister now centred on the gripper enclosure (CANISTER_X/Y_W = 0, -12);
    drive shaft kept off-centre at (-12, -11.72) inside it. Cap + wrist_plate
    parameterised with bore offsets so the lip-seal bore is off-centre while
    the cap stays centred on the body.
    - New `gripper_taper_cover()` snap-on shroud — lofted Ø100 → 108×42 rounded
    rect, 50 mm tall, 3 mm wall — covers the enclosure so the system reads as
    one smooth body from canister to fingertips.
    - Wrist plate bolt-pattern Y-coord sign fix (`cy = 12.0 - bz`) so the four
    flange bolts land on the gripper face, not in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
    [printed_adapters.py, system_assembly.py]
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2026-05-26 feat(motor/cad/adapters): model 7 mounting adapters in build123d
    7-agent concurrent CAD swarm. Each adapter is a parametric build123d
    module that mates the gripper's 4×M4 bottom flange to a specific
    arm/ROV/chassis interface family, plus a STEP + iso PNG snapshot.
    Shared gripper-side mating geometry locked in `_base.py`:
    - 4× M4 clearance at (±38, ±8, 0) on the Z=0 mating face.
    - Ø16 shaft + lip-seal clearance bore at (X=-12, Y=0) — the off-centre
    drive shaft is the geometric consequence the adapters absorb.
    - Helpers `gripper_bolt_holes()` + `shaft_clearance_bore()` import
    verbatim from `_base.py`; no agent re-derived the flange.
    P0 (ready to print):
    - `adapter_bravo7` — Reac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
    [adapter_br2_bottom_newton.step, adapter_br2_payload_skid.step, adapter_br2_roof_rack.step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]
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2026-05-26 refactor(adapters): redesign 7 adapters as Ø100 PA12-GF unibody pod pieces
    Previous adapters mated to the gripper's M4 bottom flange — but in the
    unibody (gripper + canister) configuration that flange is INTERNAL,
    captured by the wrist_plate. Andre flagged that the previous renders had
    the adapter "floating off the canister, not actually mounted onto it" and
    didn't match the unibody look.
    Redesign:
    - Each adapter now starts with a Ø100 PA12-GF pod base that visually
    continues the canister's pod_cap_shroud OD. Mating face at adapter Z=0;
    body lives in +Z.
    - Pod base carries 4× M5 clearance holes on Ø78 PCD for SHCS into the BR
    dry cap (repurposing the existing M10 penetrator hole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
    [adapter_br2_bottom_newton.step, adapter_br2_payload_skid.step, adapter_br2_roof_rack.step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]
2026-05-26 fix(render_assemblies): seat adapter on pod_cap_shroud top (Z=275, not WetLink tip Z=333)
    The adapter was rendering at world Z=333 — the tip of the WetLink penetrator
    poking up from the BR dry cap — which left a ~58 mm air gap between the
    adapter bottom face and the canister, looking like the adapter floated on
    a string above the unibody.
    WORLD_POD_CAP_TOP_Z is now 275 (the top face of the pod_cap_shroud). The
    adapter sits flush on that face.
    Also widened the pod-base cable-exit slot to Ø16 and moved it to adapter
    Y=+30 (world Y=+18), aligning with the WetLink penetrator so the cable
    exits cleanly without the adapter clashing with the penetrator body.
    [adapter_br2_bottom_newton.step, adapter_br2_payload_skid.step, adapter_br2_roof_rack.step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]
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2026-05-26 feat: P2-vs-P1 finger FEA, out-of-sample gate, rank-at-operating-force, real 3D crown FEA
    Addressing the four 'out of scope' items the prior wrap-up bracketed off:
    1. **P2-tet finger FEA** (B1, fea/scripts/solve_finger_p2.py): repeats the 2D
    plane-strain precursor with QUADRATIC triangles (P2/P1 element pair --
    locking-stable for the near-incompressible ν=0.45 problem). Same mesh,
    same St-Venant-Kirchhoff material, same BCs. Headline result:
    at the same load level, P2 reports ~50 % HIGHER peak vM than P1
    (1.001 vs 0.786 at 1.8 N; 2.915 vs 1.915 at 4.5 N; 3.388 vs 2.223 at
    4.95 N). The published 2D headline 'peak vM ≈ 2.7 MPa at 5.4 N' was
    optimistic;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
    [finger_section.step, plate_rigid_1.3mf]
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2026-05-30 fix: restore crown face teeth + make input shaft installable
    The right-angle input-drive stage had two real bugs:
    * Crown teeth swallowed -> smooth washer. _crown_gear built the ring at full
    Z-height with the 24 face teeth INSIDE that span, so they added ~0.3 mm^3 and
    the pinion just plunged into solid material. Now a thin base ring + PROUD teeth
    with open valleys; tooth top/floor are computed from the pinion so the crown
    tips clear the spinning pinion ROOT cylinder (CROWN_MESH_CLEAR) and the valley
    floor sits below the pinion tip. Teeth add ~270 mm^3; mesh overlap is now
    phase-dependent (3.0 -> 6.6 -> 3.0 mm^3) = real interleave. The pinion teeth
    were already correct (module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
    [drive_arm_L.step, drive_arm_L.stl, drive_arm_R.step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]
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2026-05-30 feat: scale grip micro-texture with GRIPPER_SCALE + export 1.5x & 2.0x variants
    Grip texture (FR_GRIP_*) now scales self-similarly with the gripper instead of
    being held at absolute size. Rationale: holding it absolute quadrupled the post
    count at 2x and made the finger build ~10x slower (2x export 58min -> 6min after
    this change). It is grip-safe: the wet-grip campaign found grip is grip-NEUTRAL
    above a ~0.3mm channel (drainage saturates), and the scaled channels stay above
    that at every scale (0.54 -> 0.81 -> 1.08mm), so coarser channels drain at least
    as well. The closed-pose finger-finger gap also scales proportionally (no
    collision). SCALE=1.0 stays byte-identical to baseline.
    Exported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
    [drive_arm_L.step, drive_arm_L.stl, drive_arm_R.step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]
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2026-06-23 feat(pins): heat-stake melt-rivet pivot pins — fix snapping barbs + wobbling axles
    Both 3D-printed pivot-pin designs failed in the field:
    - finger pins C/D: the split snap-fit barb broke instead of flexing
    - axle pins A/B: the plain dowel "sandwich" wobbled and slid out of its bore
    Both are replaced by plain PETG-HF journal pins retained by a SEPARATE printed
    cap melted onto the pin's stud with a soldering iron (thermal rivet). Retention
    is geometric — a formed head larger than the hole — so nothing flexes (no broken
    barbs) and nothing relies on friction (no pins sliding out), and it is creep-proof
    (a formed shape nested in a confining recess, not a held preload).
    gripper.py:
    - new m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
    [drive_arm_L.step, drive_arm_L.stl, drive_arm_L_x1_PA12-GF.stl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]
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2026-06-24 fix(pins): locating collar on each axle pin — stop the elements sliding axially
    The rotating elements (gear/arm at A, follower at B) rode on a bare PIN_R shank
    with ~12 mm of EMPTY pin above them, so after assembly they slid/rocked up and
    down the pin axis. Fix: a fat COLLAR on each axle pin in that empty space, just
    above its element. The element is now trapped between the back-boss face (below)
    and the collar (above) with 0.25 mm running clearance -> it spins but cannot
    slide. Feasible on a one-piece pin because axle pins insert stud-FIRST: the
    collar approaches from above and never has to pass through the element bore.
    - gripper.py: AXLE_COLLAR_R (3.05) / AXLE_COLLAR_GAP (0.25); axle_p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
    [drive_arm_L.step, drive_arm_R.step, enclosure.step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]
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
